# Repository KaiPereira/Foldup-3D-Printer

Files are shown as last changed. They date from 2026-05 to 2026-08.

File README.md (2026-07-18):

# Fold up, scissor lift, 3D Printer



This is my fold up, scissor lift, cross-cantilever 3D printer for Open Sauce 2026! It folds up into the size of a small filament box, coming in at just 200x200x75mm in form factor, and has a build area of nearly 80x80x95mm! It is a fully unique 3D printer that utilizes a Positron hotend and a custom HGX Lite bowden extruder and all of it runs off of a simple barrel-jack connector. 

## Custom Features
- Unique scissor-lift, cross-cantilever motion system
- Fits in a filament box and folds up into a 200x200x75mm form factor
- Has a build area of almost 80x80x95mm
- Runs completely off a portable barrel jack connector
- Offline printing using a MicroSD card
- Fast and efficient positron hotend with a custom HGX Lite bowden extruder
- Supports Marlin or Klipper firmware with the BTT SKR MINI E3 V3.0 motherboard
- Looks insanely cool so you can flex at hackathons

## Wiring

The electronics are pretty simple for this project:



## Assembly

### Bill of Materials (BOM)

I bought my parts from Aliexpress, Amazon and then got the aluminum plates cut by PCBWay. 

The BOM isn't too complicated and it also includes some tools that are helpful for assembly, you can access [it here](https://docs.google.com/spreadsheets/d/1xFZ-rjcnBZJ-4SHDmdkzTACUUDvWx6YCcqEs-uq4CdA/edit?usp=sharing).

### CAD

Assembling the board is fairly simple by referencing the [Onshape assembly](https://cad.onshape.com/documents/3a7b565130dc54a0f58628c0/w/db45ce09661f59e4e89ec29b/e/58f0074d6e4db55998381609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).

All the 3D printed/aluminum parts and the entire STEP for the project are accessibly in the [CAD folder](/CAD) too. 

### Firmware

You can just run Klipper firmware for the entire printer. I've left some boilerplate in the [firmware folder](/firmware)!

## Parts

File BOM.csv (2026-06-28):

Item | Amount # | CAD Cost ($) | Usage: | Link | Notes:
Miscellaneous Nuts, Bolts, Screws and Bearings
Bearings | 10 | $13.99 | Bearings for all the scissor lift joints! | https://www.amazon.ca/Pcs-608-2RS-Ball-Bearings-Pre-Lubricated/dp/B0GVV2QJ5G
D8 M6, 16mm Shoulder Bolts | 8 | $6.34 | Shoulder bolts to hold the scissor bearings | https://www.aliexpress.com/item/1005009104127830.html?curPageLogUid=jj2cmFYo2cBi
M3x22mm + 6mm Male to Female Standoff | 4 | $5.82 | These are the special standoffs for spacing the bed from the base of the printer | https://www.aliexpress.com/item/1005004553969515.html?productId=1005004553969515
M3 Nuts | 100 | $3.28 | These are for if I need to lock any of the M3 bolts | https://www.aliexpress.com/item/1005008625622586.html?curPageLogUid=QGnkjvTtCtBt
M8x12mm, 0.5mm Steel Shims | ? | $4.99 | Steels shims to space out the shoulder bolts from other parts | https://www.aliexpress.com/item/1005001878385012.html?curPageLogUid=dnKhIt84hhRM
M6x7.5mm, 10mm Heatset Inserts | 8 | $8.21 | Heatset inserts for securely fastening the M6 bolts | https://www.aliexpress.com/item/1005012009793893.html?curPageLogUid=EhZVAJwp2ZOt
M3x5mm, OD 4.5mm, heatset inserts | 1 | $0.00 | This is the heatset insert for the bowden extruder, tensioner screw |  | DOUBLE CHECK I HAVE
M3x12mm/0.5", socket head cap screws |  | $32.99 | These are the screws for the moving scissor lift carriages | https://www.amazon.ca/Pieces-Screws-Stainless-Washers-Assortment/dp/B09YM913D4?sp_csd=d2lkZ2V0TmFtZT1zcF9hdGY
M3x25mm/1", socket head cap screws |  |  | These are the screws for the STATIC scissor lift carriages
M3x10mm/0.375", socket head cap screws |  |  | These are the screws for the linear rails and other parts
M3x20mm/0.88", socket head cap screws |  |  | These are the screws for the linear rails and other parts
M3x6mm/0.25", socket head cap screws |  |  | For the Y carriage, bolting a linear rail from underneath
M2.5x14mm, socket head cap screws |  | $16.99 | These are the screws for mounting the fan to the positron hotend | https://www.amazon.ca/mxuteuk-480Pcs-Stainless-Assorted-G035-M2-5/dp/B0C7ZRTH3Q?sp_csd=d2lkZ2V0TmFtZT1zcF9hdGY
M2.5x25mm, socket head cap screws |  |  | These are the M2.5 cap screws for mounting the extruders, Nema 11 to the top plate and extruder to the nema 11 from the bottom |  | The length of these can also be changed to be more global
M2.5x8mm, flat head socket cap screws |  | $10.48 | These are the countersunk flat head cap screw for mounting the hotend plate to the positron hotend from the bottom | https://www.aliexpress.com/item/1005012356242603.html?src=google | The length of these can be changed
M3x6mm, flat head socket cap screws |  |  | These are the flat head screws for one of the linear rail mounts for the hotend plate and X axis leadscrew linear rail mount
Stepper Motors
11HS2810-T5X4 | 2 | $85.06 | These are the Nema 11's for my X/Y axes with integrated leadscrews! | https://www.aliexpress.com/item/4000511206852.html?src=google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
35HS34-150N52 | 2 | $100.97 | These are the 2 Nema 14's for the Z axis with integrated leadscrews! | https://www.aliexpress.com/item/1005003623639443.html?curPageLogUid=7hzoTjL6dFmj
11HS2810 | 1 | $26.38 | This is the Nema 11 for the extruder | https://www.aliexpress.com/item/1005005224703770.html?curPageLogUid=pCFCBT3bWVn4
Bed heater, PEI, thermistors and cork
24V 100x100mm Silicone Bed Heater | 1 | $14.37 | This is the heater for the 3D printer bed. The heater is a bit smaller than the PEI sheet, so there's a bit of unheated space, but it'll be fine | https://www.aliexpress.com/item/1005004051777634.html?curPageLogUid=zmOjdQupdsw8
x4 NTC100K XH2.54 1M B3950 | 4 | $4.99 | Thermistors for the bed and MISC | https://www.aliexpress.com/item/32839681093.html?curPageLogUid=jNLwWSrSVgI3
120x120mm Black PEI sheet with base | 1 | $12.48 | This is the PEI sheet for my printer! It's a bit larger than the heater so there's a bit of unheated space on it | https://www.aliexpress.com/item/1005008559095059.html?curPageLogUid=Tv17pzmPMbsf
2x300x600mm cork adhesive | 1 | $10.48 | This is cork adhesive to thermally space the metal base from the metal bed heat spreader | https://www.aliexpress.com/item/1005009769388038.html?curPageLogUid=VJbhgLvk7WmK
Electronics and power
BTT SKR MINI E3 V3.0 | 1 | $39.24 | This is my 3D printer motherboard, with shared Z axis steppers | https://www.aliexpress.com/item/1005003521537547.html?src=google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
24V, 8A DC Power Adapter (barrel jack) | 1 | $29.99 | This will go into the barrel jack mount connector to be separated into wires which will plug into the MOBO | https://www.amazon.ca/Adapter-100-240V-Converter-Voltage-Transformer/dp/B0CBP2KXFB | Amazon because it's safer, more reliable and the price difference isn't crazy
20 AWG, Barrel Jack Mount Connector | 1 | $3.81 | This is the barrel jack mount connector which will separate the power into the 2 wires for the MOBO | https://www.aliexpress.com/item/1005008014808796.html?curPageLogUid=eLFrNRpNAY51 | Just in case that the above barrel jack connectors don't work
Extruder, gears, PTFE
HGX Lite Gear Kit | 1 | $14.28 | These are all the components I need to construct my custom extruder :D | https://www.aliexpress.com/item/1005007313875922.html?src=google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
5mm/0.5M 17T Set Screw Gear | 1 | $3.70 | This is the gear that'll attach to the stepper on the extruder in order to drive motion to the reducing gear | https://www.aliexpress.com/item/1005006755339441.html?scm_id=1007.40050.354490.0&scm-url=1007.40050.354490.0
PTFE Quick Connector | 1 | $3.54 | These are extra PTFE quick connectors for the output of the bowden extruder | https://www.aliexpress.com/item/1005006648870088.html
2m PTFE 2.5x4mm and PTFE cutter | 1 | $6.49 | This is all the PTFE for the printer and extra because I've never worked with PTFE before along with a flush cutter for precise cutting | https://www.aliexpress.com/item/1005010585958289.html?curPageLogUid=Y93xcFtSckLr
Hotend and fans
Positron Hotend | 1 | $0.00 | This is the hotend I'll be using! I got it sponsored from LDO Motors, and the Funssor one is another option if you'd like a cheaper printer | https://lemontron.com/lemontron-rev-e/bom/positron/positron-hotend/
2510 Fan | 1 | $3.81 | This is the main fan for the positron hotend heatsink | https://www.aliexpress.com/item/1005007437708739.html?curPageLogUid=muacLadZQQRl
3010 Blower Fan | 1 | $5.10 | This is the blower fan for cooling the filament once it gets extruded | https://www.aliexpress.com/item/1005007175610610.html?curPageLogUid=ViSXO0x8tRUI
Linear Rails
140mm MGN9H Rails | 4 | $108.36 | These are all the linear rails bought at a standard 150mm size, and are then going to be cut down for my build | https://www.aliexpress.com/item/1005009577277063.html?curPageLogUid=LKLMsBYxQMyv
124mm MGN9H Rails | 2 |  |  | https://www.aliexpress.com/item/1005009577277063.html?curPageLogUid=LKLMsBYxQMyv
134mm MGN9H Rails | 1 |  |  | https://www.aliexpress.com/item/1005009577277063.html?curPageLogUid=LKLMsBYxQMyv
158mm MGN9H Rails | 1 | $18.18 | These are the same rails, but I need to buy the 200mm version to cut down to 158mm | https://www.aliexpress.com/item/1005009577277063.html?curPageLogUid=LKLMsBYxQMyv
Aluminum Plates
120x120mm, 1/8", Custom Aluminum Bed | 1 | $110.00 | The aluminum heat spreader for the bed | PCBWay
180x180mm, 1/8", Custom Aluminum Base Plate | 1 |  | This is the base plate for the entire 3D printer
180x180mm, 1/8", Custom Aluminum Top Plate | 1 |  | This is the top plate for the entire 3D printer
1/8", Custom Aluminum Scissor Lift Arm | 4 |  | These are all the scissor-arms for the 3D printer
Miscellaneous Extra
1kg Green PETG | 1 | $23.99 | This is all the filament for my printer, I'll probably prototype using a different color I already have but I want all green | https://www.amazon.ca/Polymaker-Filament-Strength-Excellent-Compatible/dp/B0FG3KK26X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
Loctite Blue 243 | 1 | $16.61 | Loctite for the shoulder bolts and other components | https://www.amazon.ca/Threadlocker-Strength-Fasteners-Against-Losening/dp/B0C8Z81WQL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
 | Total Theorized Cost (CAD): | $730.93
 | Total Theorized Cost (USD): | $514.94
 | Aliexpress Cart (CAD): | $512.15
 | Amazon Cart (CAD): | $134.56
 | PCBWay Cart (CAD): | $0.00 | Sponsored
 | Actual Cost (CAD): | $646.71
 | Actual Cost (USD): | $455.61

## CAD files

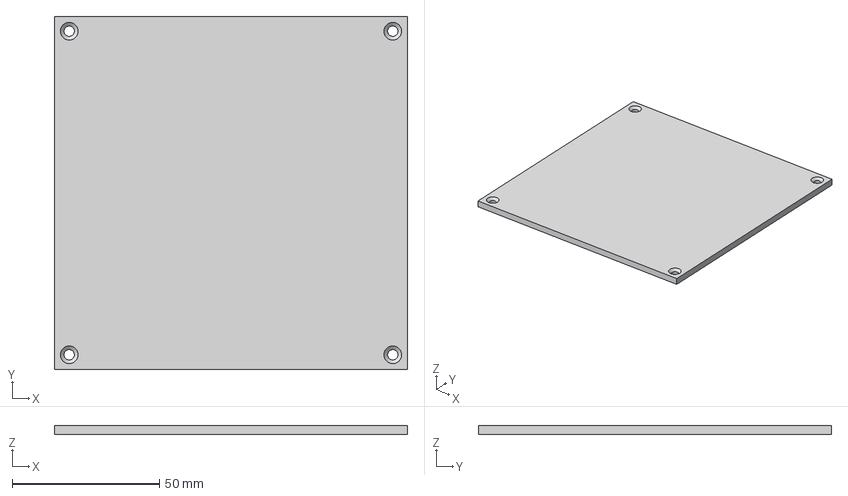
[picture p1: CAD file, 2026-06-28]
CAD/Aluminum Plates/BED_SPREADER.step
120.0 x 120.0 x 3.17 mm

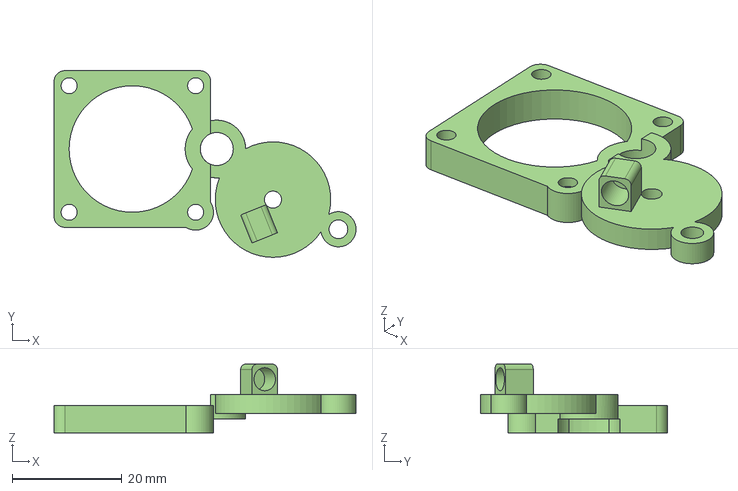
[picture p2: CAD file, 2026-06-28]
CAD/Extruder/Top Extruder Housing.step
54.9 x 34.0 x 12.5 mm

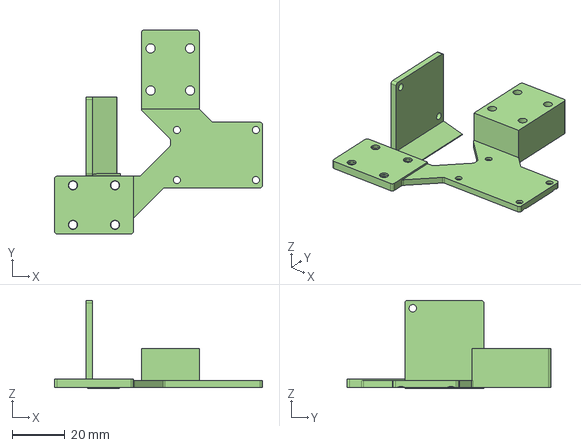
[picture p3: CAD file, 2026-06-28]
CAD/Misc/Hotend Cross-Cantilever Mount.step
79.0 x 77.5 x 33.5 mm

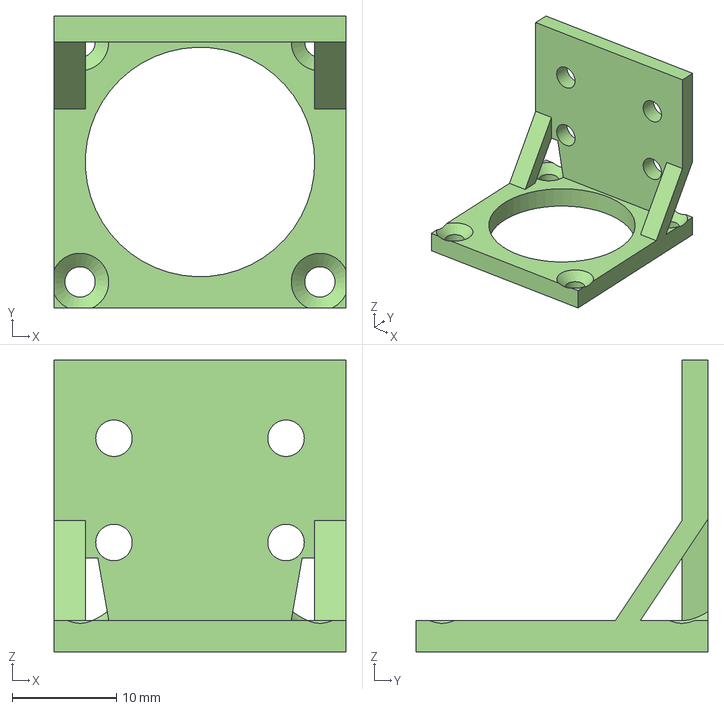
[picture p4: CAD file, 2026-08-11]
CAD/Motor Mount/Top Nema 11 Motor Mount.step
28.0 x 28.0 x 28.0 mm

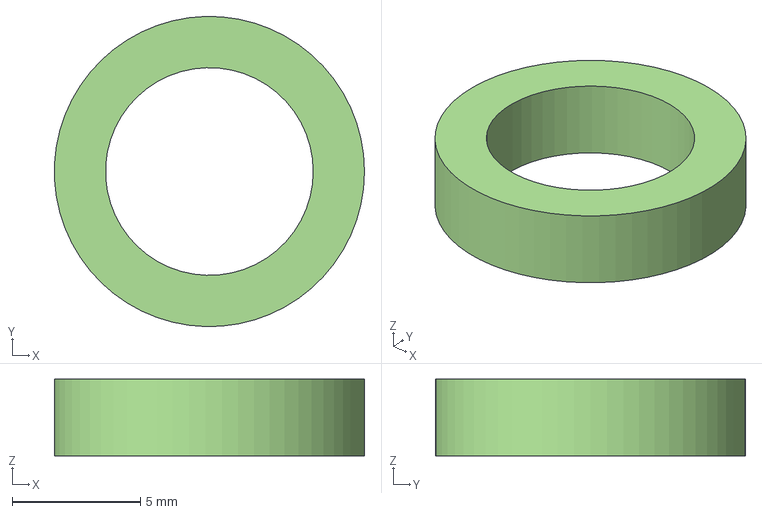
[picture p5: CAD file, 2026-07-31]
CAD/Scissor Lift/Scissor Lift Arm Spacer.step
12.1 x 12.1 x 3.00 mm

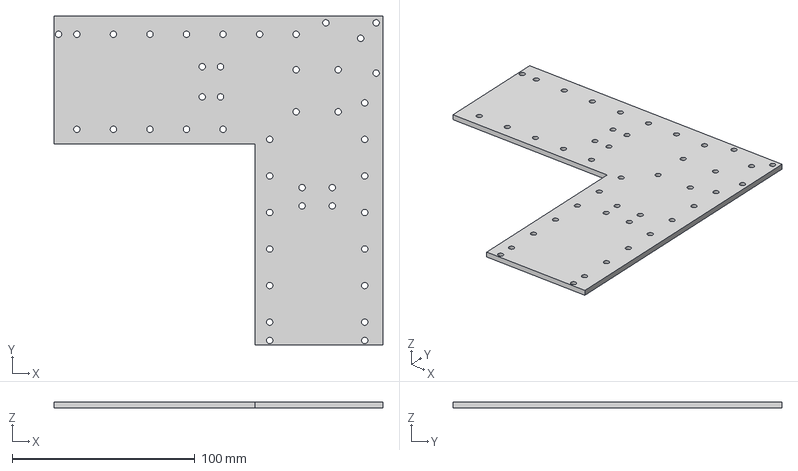
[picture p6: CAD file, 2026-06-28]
CAD/Aluminum Plates/TOP_PLATE.step
180.0 x 180.0 x 3.17 mm

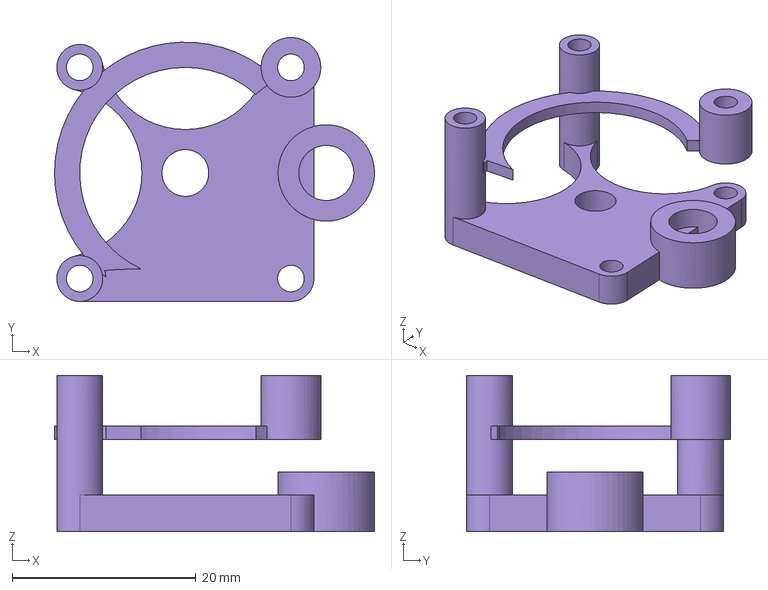
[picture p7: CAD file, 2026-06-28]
CAD/Extruder/Bottom Extruder Housing.step
34.8 x 28.8 x 17.0 mm

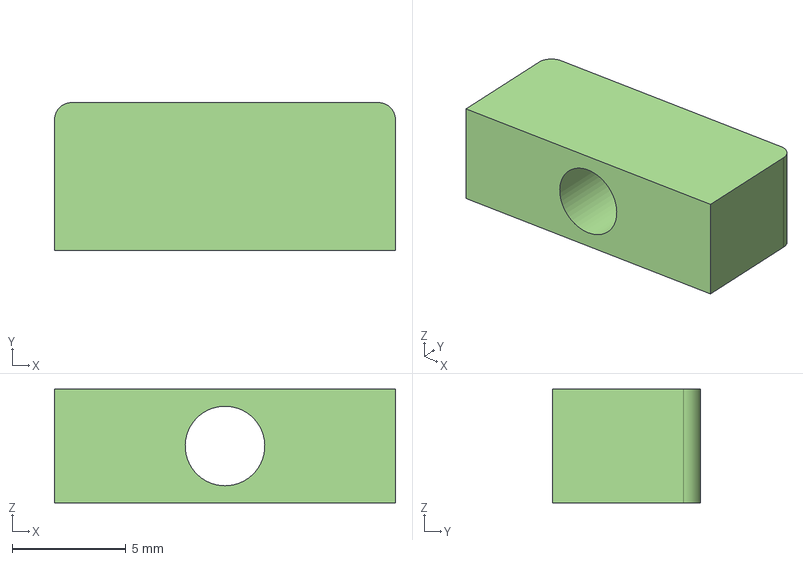
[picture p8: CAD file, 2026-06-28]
CAD/Misc/Linear Rail Endstop.step
15.0 x 6.50 x 5.00 mm

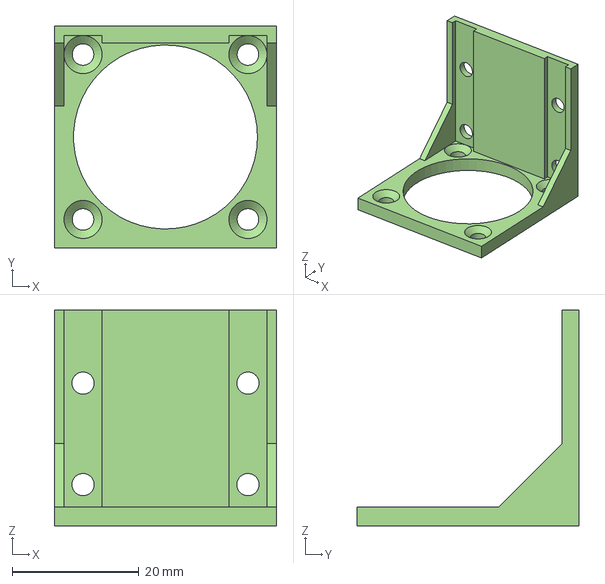
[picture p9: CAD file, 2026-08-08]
CAD/Motor Mount/Bottom Nema 14 Motor Mount.step
35.0 x 35.0 x 34.0 mm

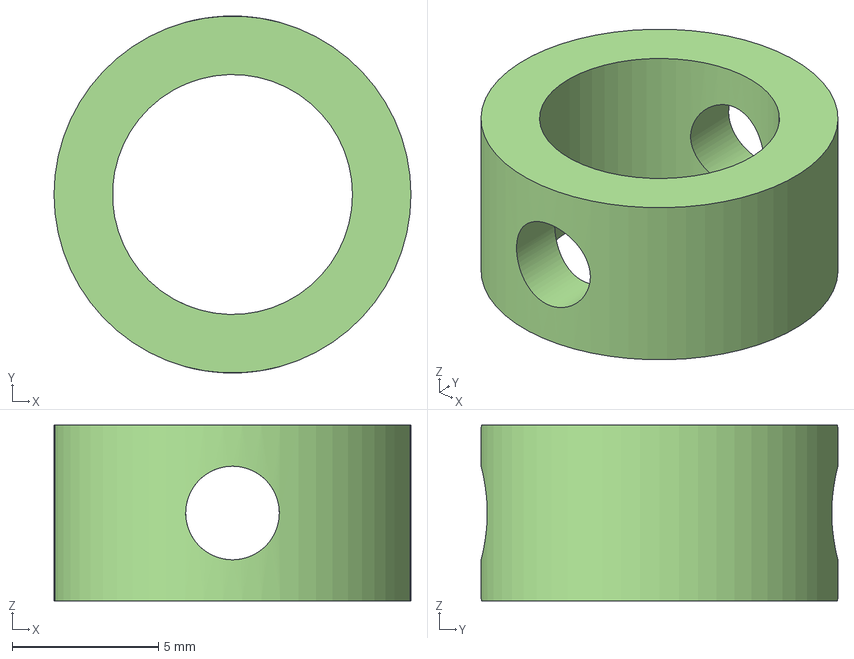
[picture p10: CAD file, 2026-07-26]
CAD/Scissor Lift/Center Scissor Arm Axle Retainer.step
12.2 x 12.2 x 6.00 mm

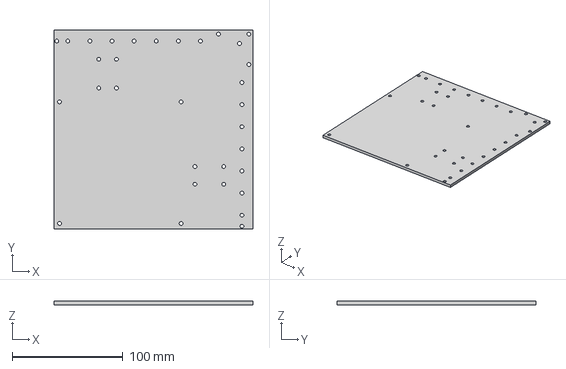
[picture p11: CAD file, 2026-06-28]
CAD/Aluminum Plates/BASE_PLATE.step
180.0 x 180.0 x 3.17 mm

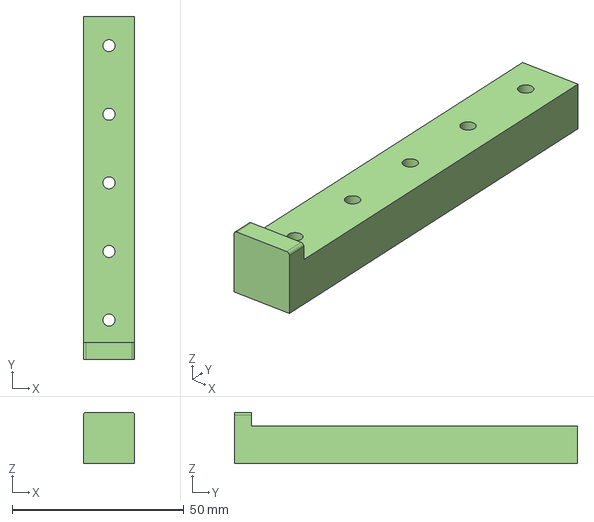
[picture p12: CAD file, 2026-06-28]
CAD/Axes/X-Axis Spacer.step
15.0 x 100.0 x 15.0 mm

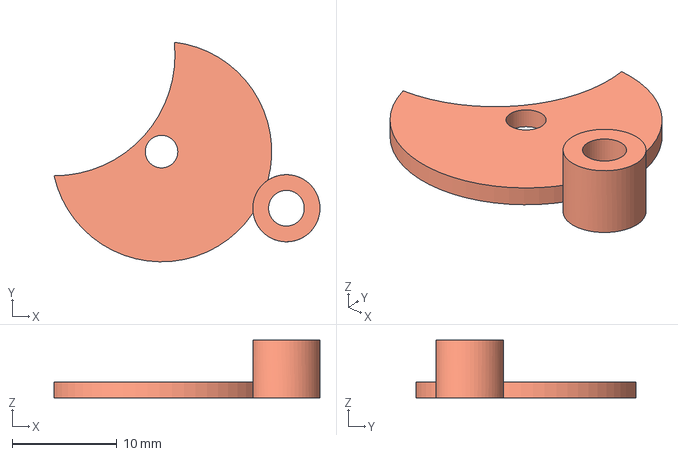
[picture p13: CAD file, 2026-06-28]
CAD/Extruder/Top Extruder Housing - Part 3.step
25.3 x 20.9 x 5.50 mm

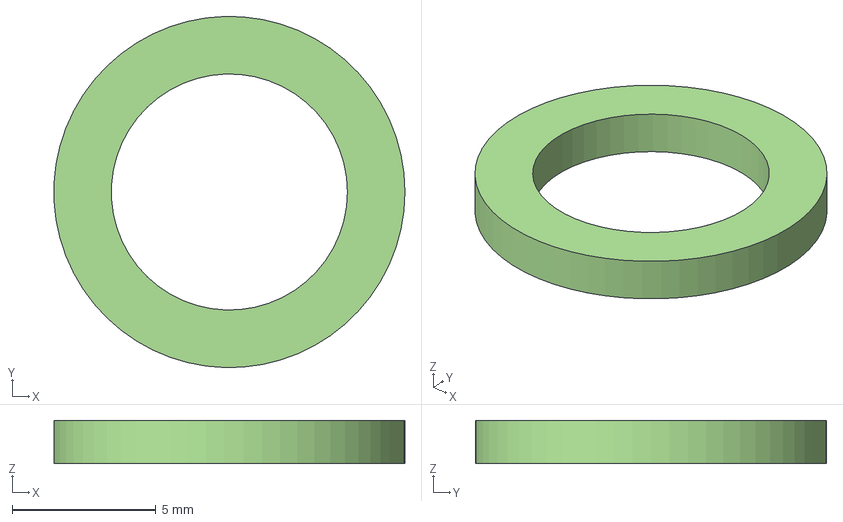
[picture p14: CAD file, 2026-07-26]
CAD/Scissor Lift/Center Scissor Arm Axle Spacer.step
12.2 x 12.2 x 1.50 mm

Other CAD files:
CAD/Aluminum Plates/SCISSOR_ARM.step
CAD/Extruder/Top Extruder Housing - Part 2.step
CAD/Scissor Lift/Center Scissor Arm Axle.step
CAD/Extruder/Top Extruder Housing - Part 4.step
CAD/Axes/X-Axis Leadscrew Mount.step
CAD/Axes/Y-Axis Leadscrew Mount.step
CAD/Scissor Lift/Bottom Scissor Lift Static Mount.step
CAD/Scissor Lift/Top Scissor Lift Static Mount.step
CAD/Scissor Lift/Top, Z-Lift, Carriage Mount.step
CAD/Scissor Lift/X Axis, Z-Lift, Leadscrew Carriage.step
CAD/Scissor Lift/Y Axis, Z-Lift, Leadscrew Carriage.step

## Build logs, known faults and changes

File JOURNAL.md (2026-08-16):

---
title: Foldup 3D Printer
author: Kai Pereira
description: This is my folding, scissor lift, cross-gantry 3D printer I'm working on for Open Sauce 2026!
created_at: 2026-5-6
---
## An idea was born! - 7 Hours

I design a lot of circuit boards that I do a lot of basic CAD for too. Like if I ever design a keyboard, I'll make a keyboard case, if I make a radio I make a little weather station out of it, etc.

Last summer, I designed my own 3D printer motherboard, and it's made me really antsy to design my own foldup printer! So; I've spent quite a few hours (and a day of skipping school) to come up with the exact type of foldup mechanism I want to do, alongside some other cool specs for it!

My process was fairly simple:
- I wanted to have a decent amount of bed area for if I brought it to hackathons and needed to print something a bit larger
- I wanted it to be able to fit inside of a filament box so it's easy to transport
- Should be made using off-the-shelf parts, and the design shouldn't be insanely overly complex.

After many hours, I came up with my brain-child! A folding, scissor lift, cross/double cantilever 3D printer. It's essentially a combination of this cross-cantilever, and the X-printer:

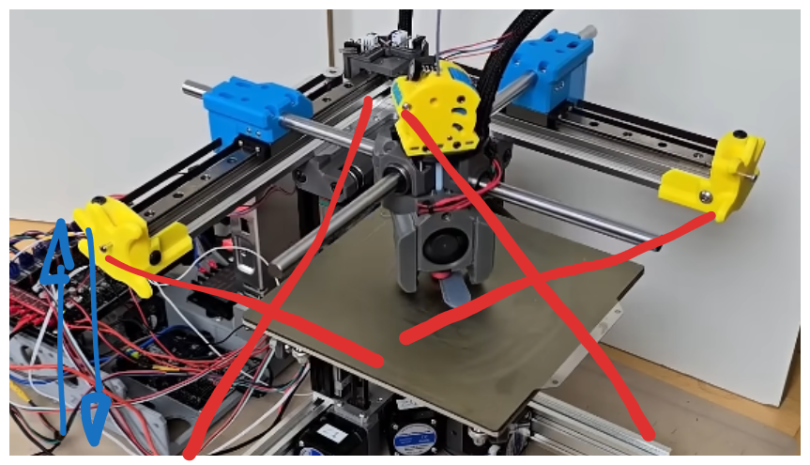
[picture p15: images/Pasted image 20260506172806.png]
Pasted image 20260506172806.png


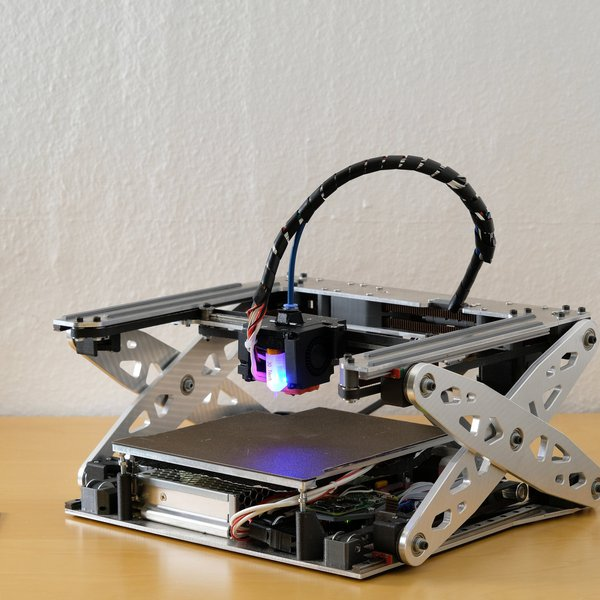
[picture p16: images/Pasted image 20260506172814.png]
Pasted image 20260506172814.png


It took me a really long time to come up with this sort of concept, but I think it'll be insanely cool, a bit complicated and also sacrificing a bit of bed space, but worth it for the insanely cool project!! 

I went through about 10 different concepts, and while some would definitely work better, I think this one is the coolest by far!

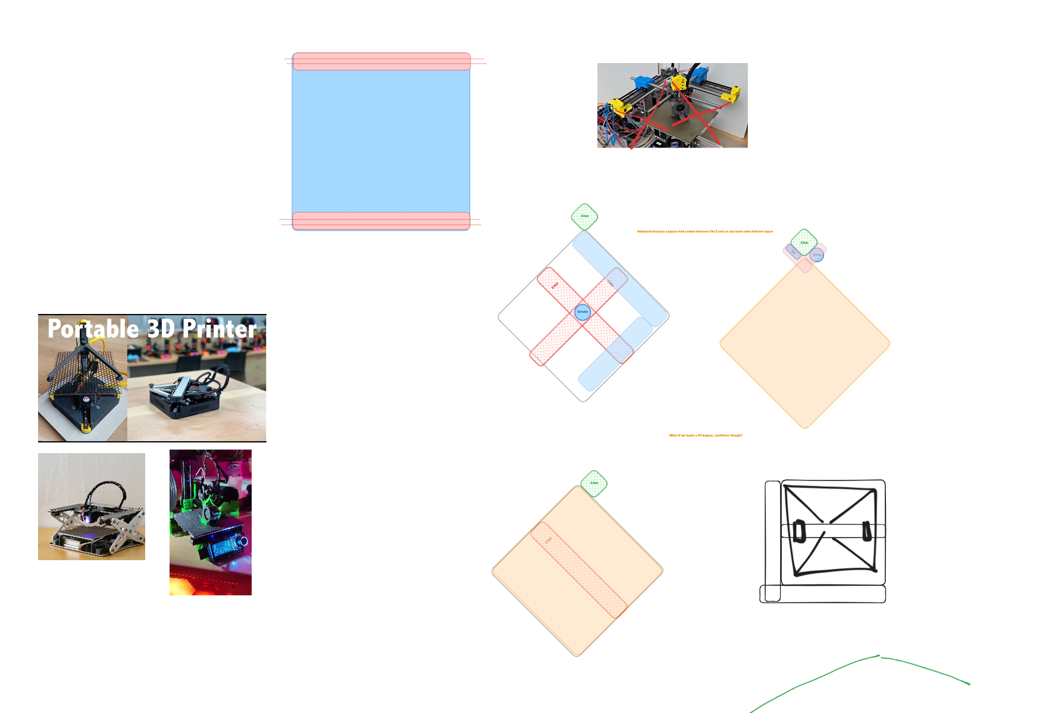
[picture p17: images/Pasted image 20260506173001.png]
Pasted image 20260506173001.png


So let's get into designing this thing!!

## Setting up my CAD workspace and planning - 6 Hours

I like to spend a lot of time thinking exactly how something will come together before putting it actually together, so the next thing I did was think about what parts I wanted to create the base out of and then build it up from them. 

I initially wanted to go with an extrusion approach and even had a pretty good plan for it, but it had some major problems:
- The extrusion was quite tall, so I wouldn't be able to mount the rails on the top faces of the extrusion, or much else so it would be really hard to build a stable printer
- It would be difficult to mount electronics in such a compact frame, and it might be kind of difficult to cut and assemble the entire thing in such a small area.
- Mostly rigidity concerns, I would be working against gravity instead of with it, and the space constrains were really bad.

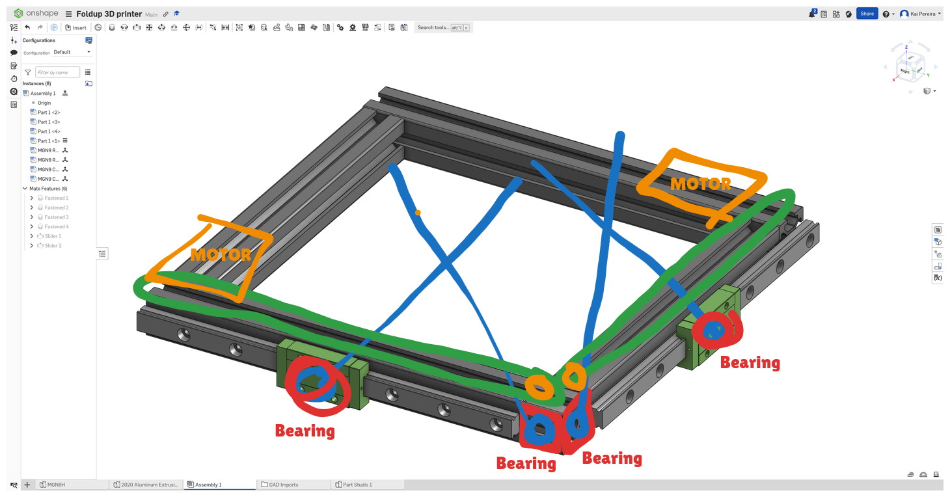
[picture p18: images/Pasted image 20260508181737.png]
Pasted image 20260508181737.png


So i decided to pivot to using 1/8" aluminum plate, just like the X printer, and I came up with a really solid plan for how I want it to work!

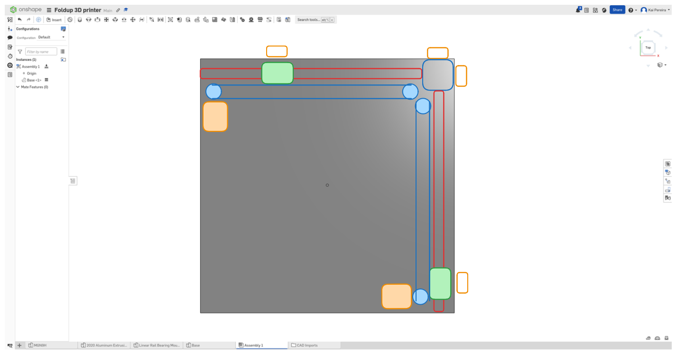
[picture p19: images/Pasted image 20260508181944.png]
Pasted image 20260508181944.png


Nothing's labelled too well but essentially, this gives me a lot of height to work with so I can mount rails to the top and everything else.

Now that I had an actual plan for how I wanted to construct this thing, and a really good vision, I needed to get the basic components in. So I made dynamic models of rails, extrusions, added in bearing models, base plate, just some stuff that would be nice to be able to dynamically add into my model.

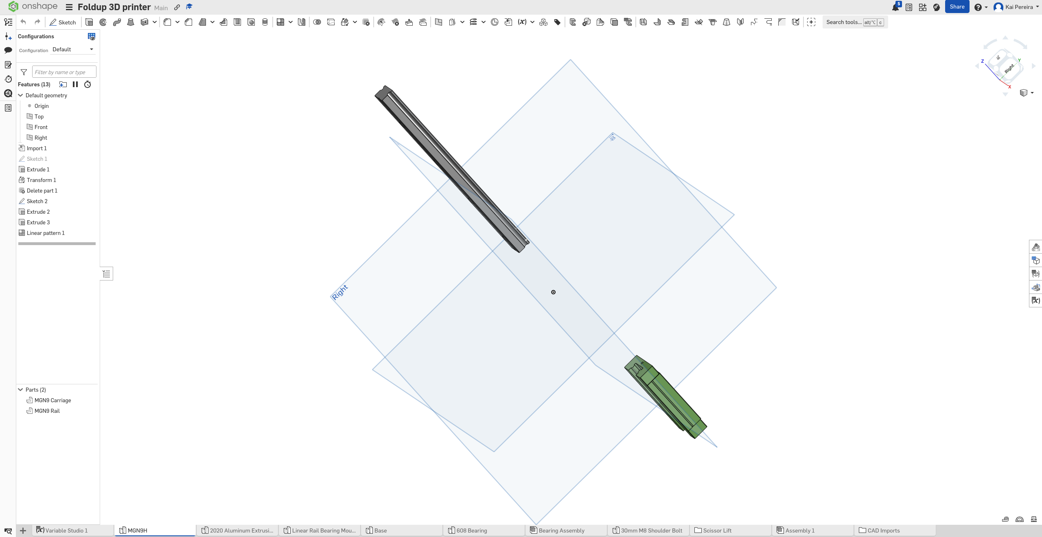
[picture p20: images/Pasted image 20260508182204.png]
Pasted image 20260508182204.png


I did a bit of researching and also decided to use 608 bearings for the scissor lift because they're really accessible, commonly used and a good size. And I also figured out that I wanted to mount my bearings using shoulder bolts, because they would fit really nicely, and they're super strong and polished!

So with all that thinking out of the way, we can get a bit more into designing this thing! 

## Basic scissor lift CAD - 7 Hours

Now that I have lots of the basic components like rails, bearings, and had an idea of the type of mounts I wanted to make, I could actually work on the scissor lift!

The first thing I did, was I made a static mount for the 2 scissor lifts to be fixed to, and then a moving carriage, could move the second part of the scissor lift, allowing it to go up and down.I decided to use a heatset insert + shoulder bolt method because the tolerances are really tight for the bearing to attach onto and it can stiffly attach into the 3D printed block.

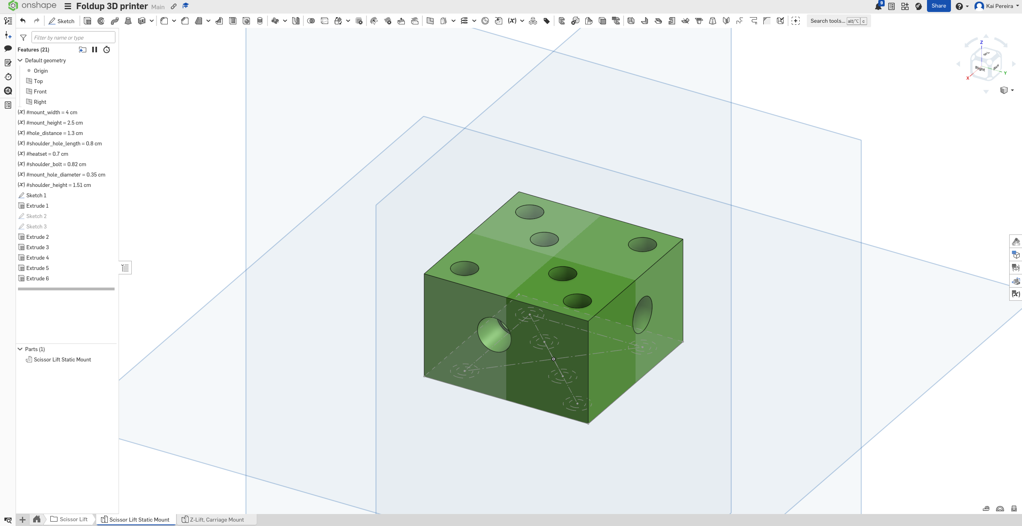
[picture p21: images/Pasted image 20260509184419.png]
Pasted image 20260509184419.png


I've also decided to actively start a BOM, so that I didn't accidentally forget parts, and so I could have all the dimensions, concrete.

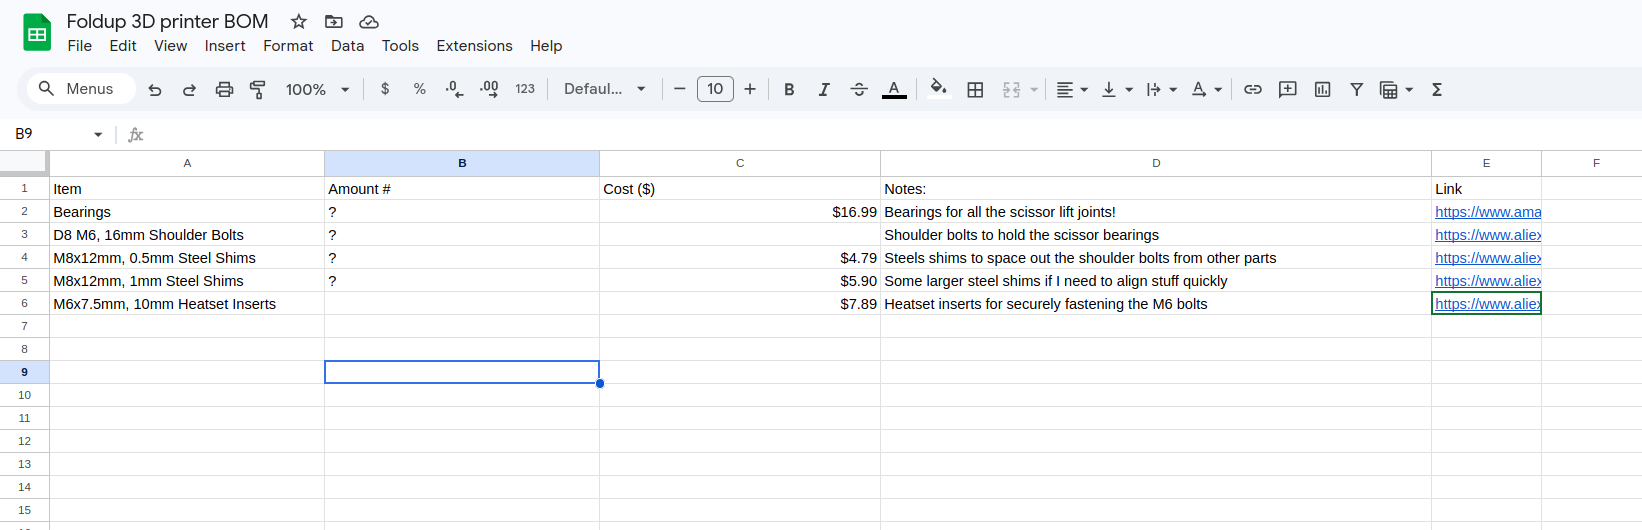
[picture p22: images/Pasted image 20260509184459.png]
Pasted image 20260509184459.png


It wasn't just a smooth process towards creating my mount, but instead lots of revisions and reflecting, while constantly importing the stuff into my assembly and seeing how nicely it fit in.

Next, I made the moving carriage mount for the scissor lift:

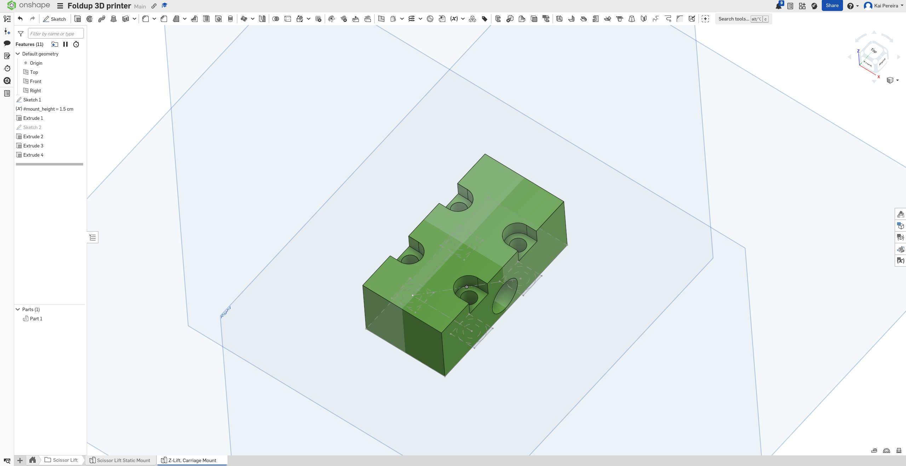
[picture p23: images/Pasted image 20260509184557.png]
Pasted image 20260509184557.png


I'm trying to stick to using M3 bolts for most of this project to minimize my BOM, so you'll notice lots of these components use the same clearances.

And then after lots of revisions, I finally have a simple linear motion system for my scissor lift!

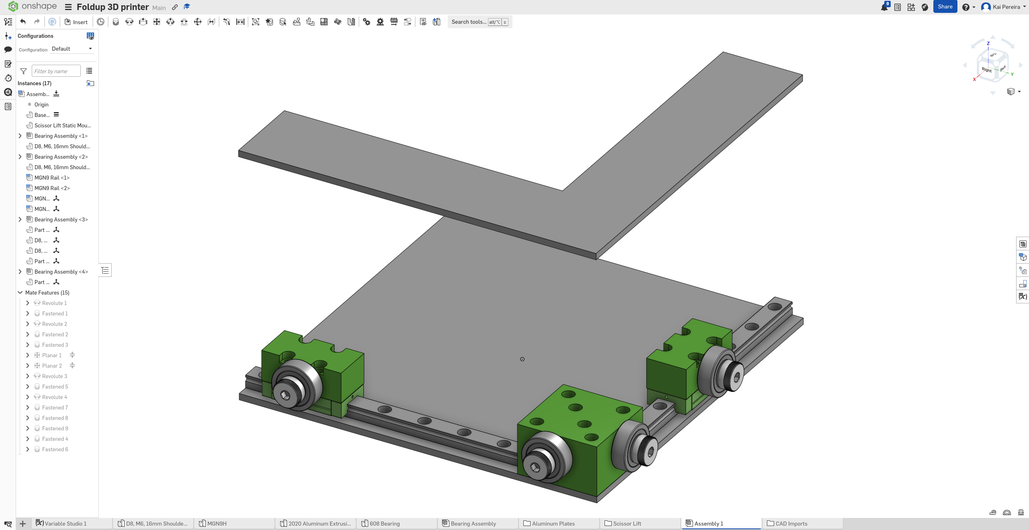
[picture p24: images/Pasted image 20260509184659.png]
Pasted image 20260509184659.png


And then finally, I can just repeat this linear motion system on the top to get my scissor lift motion down!

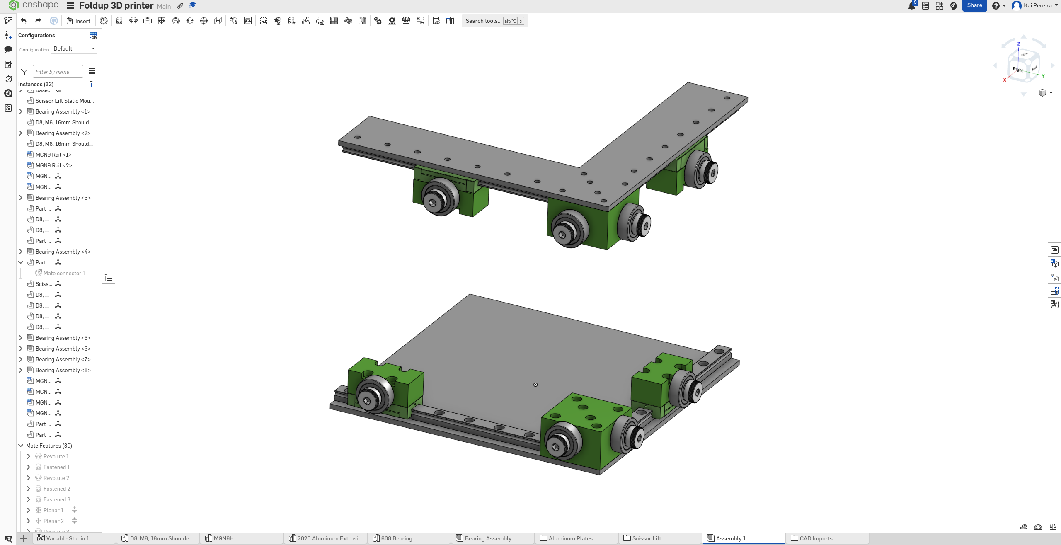
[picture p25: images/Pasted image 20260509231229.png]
Pasted image 20260509231229.png


But this does pose an interesting problem now, because I can't mount the cross-cantilever rails to the top of the plate, or else the whole thing will be too tall, and if I mount it to the bottom of the plate, next to the scissor lift motion, it'll be shorter which also isn't ideal.

So tomorrow, I'll have to figure out this tricky problem, and then I'll also hopefully add in the actual scissors too!

## Scissor lift arms, nuts and bolts - 5 Hours

Now that I have the scissor lift motion system, I can actually add in the arms! 

I decided to keep the material on the arms to be that 1/8" aluminum plate I'm using for the base and top plate, to minimize my BOM, and also because it'll be perfectly fine and 4 plates shouldn't be bending too much. It's also much lighter, so there's less stress on the joints, which is very convenient!

I did a basic model of the scissor arms first so I could get an idea of how they'll fit, and I think it turned out pretty nice!

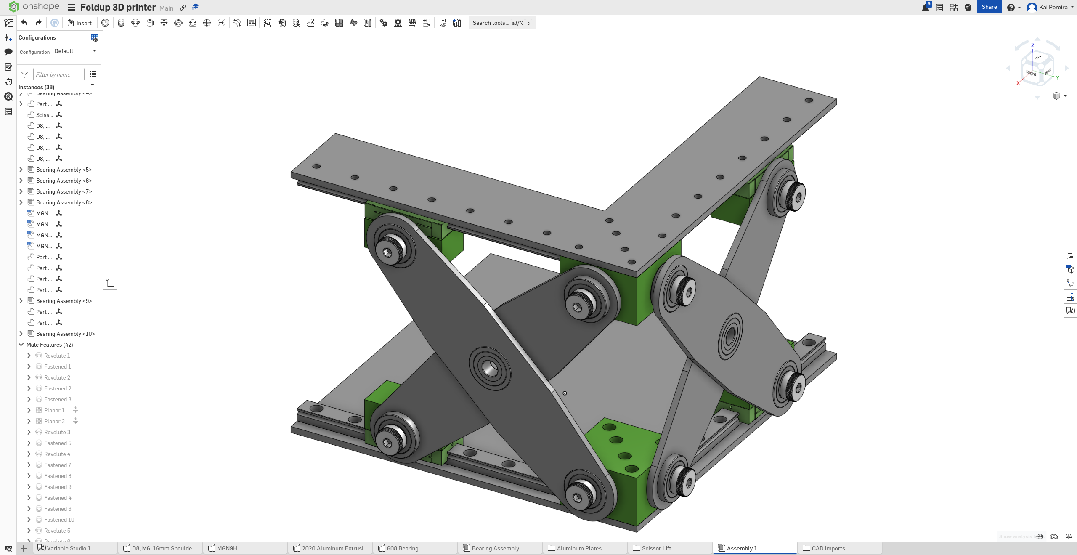
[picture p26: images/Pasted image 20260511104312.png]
Pasted image 20260511104312.png


This gives me about 11cm of Z motion, but I think I can optimize it even more for up to 12/13cm, which I think is pretty good, considering this printer is under 20x20cm! The tolerances are pretty tight and I used -0.001" for the 608 bearing so it's a nice press-fit, and I can thermally expand it if needed.

This only gives me about a mm of spacing which is really tight though, but I think it'll be fine, and might honestly keep everything together, nice and rigidly.

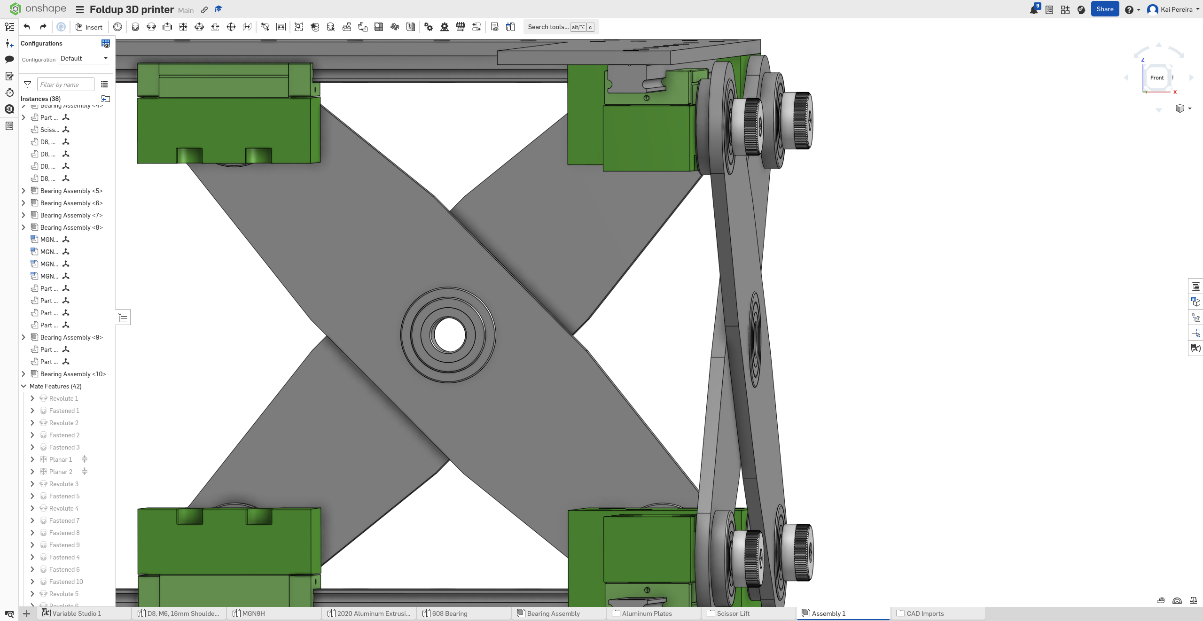
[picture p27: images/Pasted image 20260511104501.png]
Pasted image 20260511104501.png


And now that I have my scissor arms in, let's actually add in all the nuts and bolts to hold together this mechanism together!

I already had all the holes and counterbores for my socket head cap screws (which are really good for rigidity and vibrations), so it was a matter of just adjusting stuff so they fit in nicely with what I was ordering!

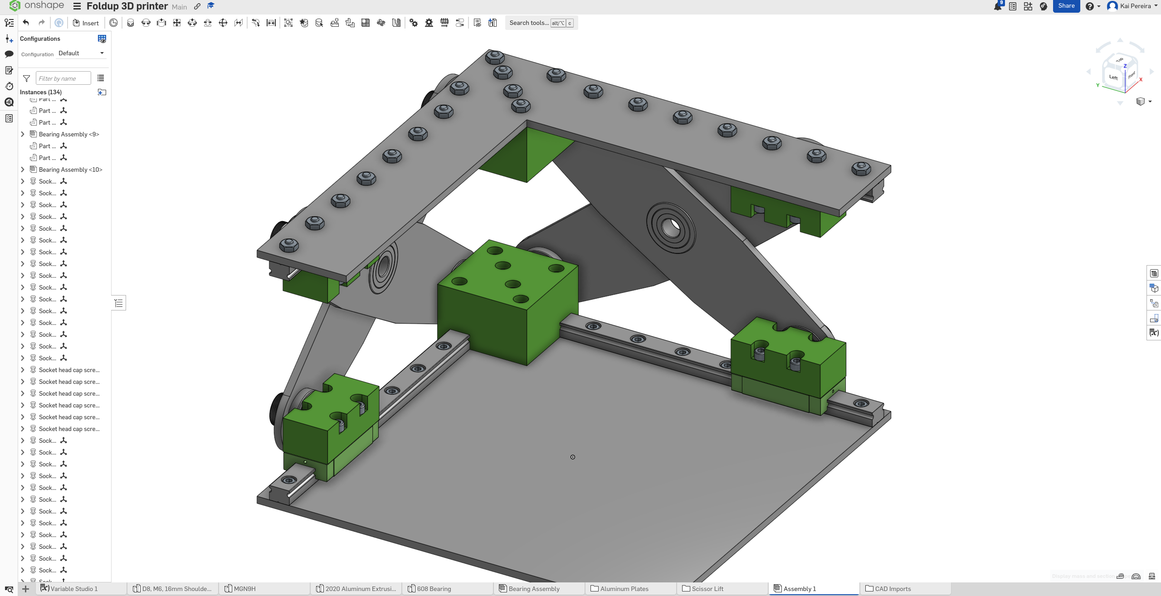
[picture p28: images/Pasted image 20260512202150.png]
Pasted image 20260512202150.png


All the screws are just M3 socket head cap screws which makes the BOM nice and minimal, and they're just of sizes 10mm, 12mm and 25mm!

Now that I have this the actual linear motions parts for this mechanism, I need to make the moving parts, so let's do that next!

## Belts, idlers, drivers and planning - 6 Hours

Now coming into this project, I had no clue how belts actually worked, or their standard sizes. So this led me down the rabbit holes of belts!

The first thing is that 3D printers typically used GT belts and specifically GT2/GT1.5 belts which have their respective pitches. I've decided to use GT2 belts, because they provide more rigidity, being bigger.

Next, there's the idlers and drivers/timing pulley. The idler simply sits fixed on one end so the belt can move freely and then the driver spins from a stepper to drive the whole belt!

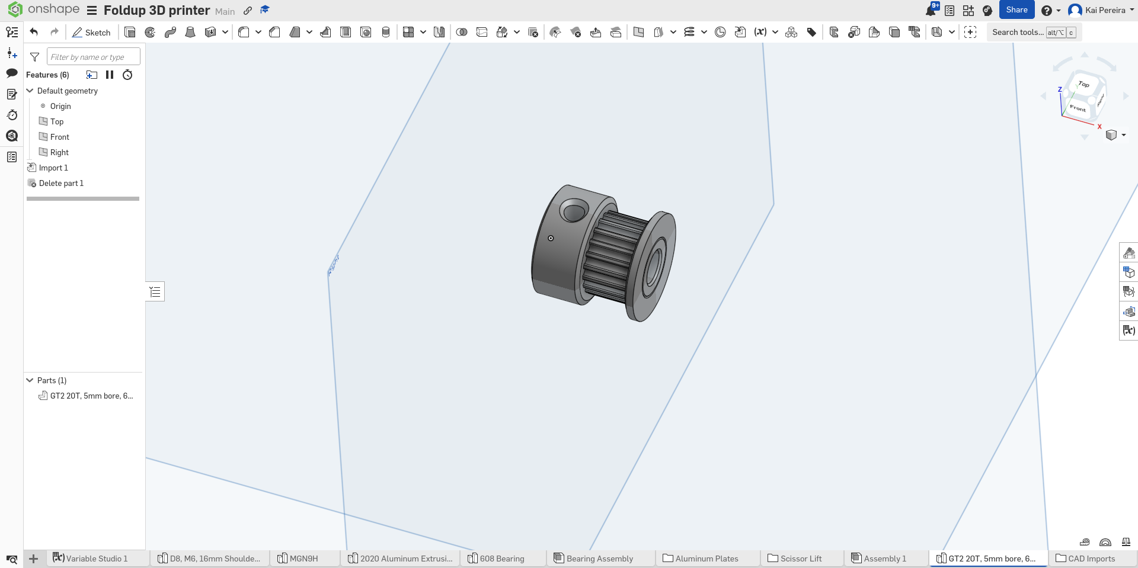
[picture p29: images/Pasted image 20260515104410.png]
Pasted image 20260515104410.png


The driver is attached directly on to the shaft of the Nema 17 and then you can tighten it using the set screws in the driver. 

Next, I wanted to plan out how I was actually going to put on the X/Y axis, so that it wouldn't intersect with any of my belts.

I was on a flight during this process, and decided that mounting them perpendicular to the top plate would be best to minimize space, but I haven't 100% decided on it yet:

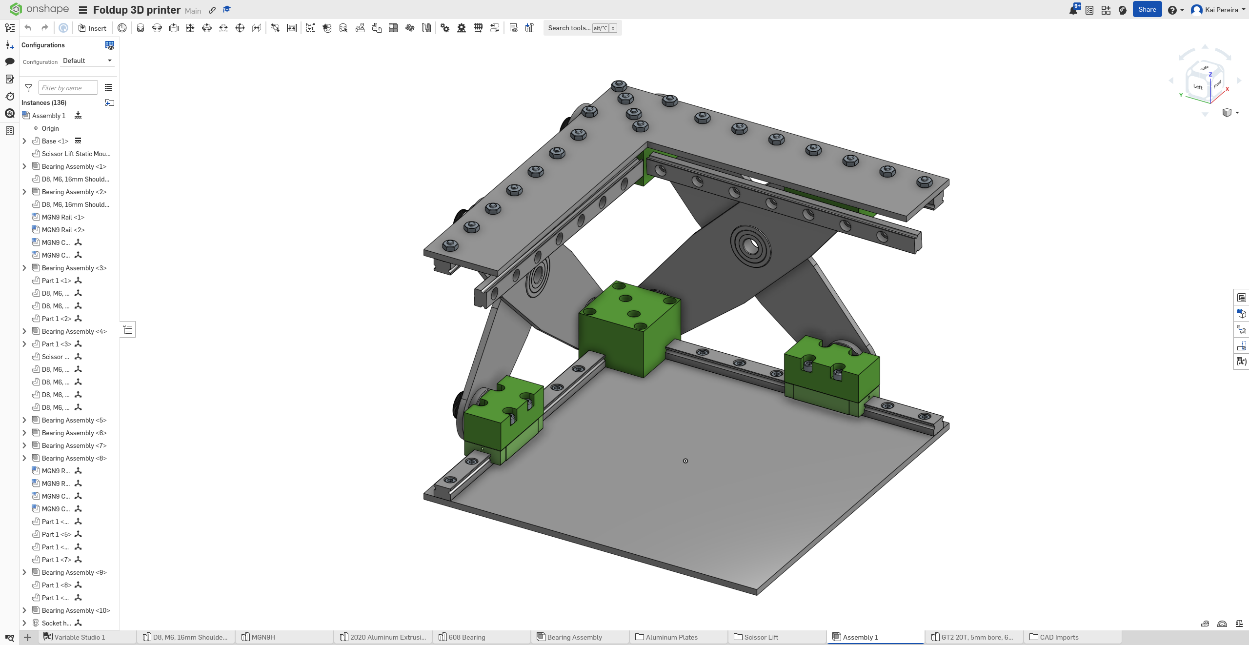
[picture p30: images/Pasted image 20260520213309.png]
Pasted image 20260520213309.png


Now I also need to decide on what type of steppers I want to use!

But before I do that, I think it'll be a good idea to actually figure out how everything will fit onto the printer. I've come up with 2 main concepts that would both work fairly well.

The first system is a fairly complicated, belt-only system:

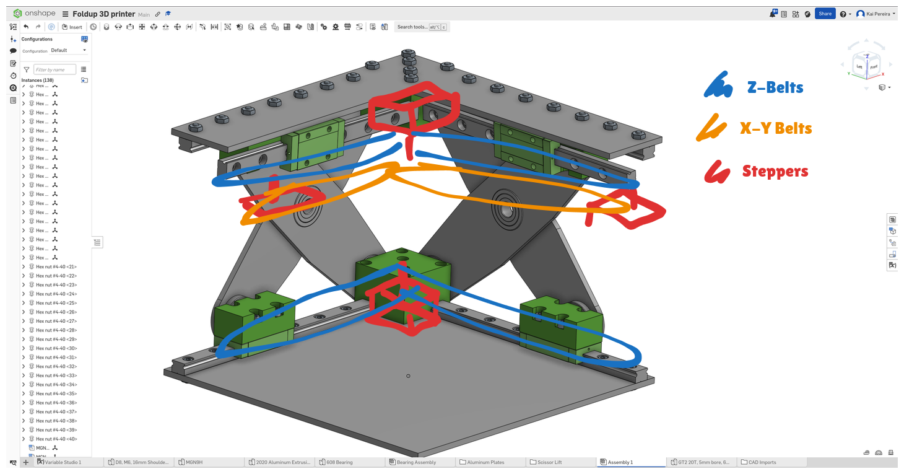
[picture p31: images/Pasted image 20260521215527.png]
Pasted image 20260521215527.png


This one has the advantages of looking cool, and probably being fairly rigid, but it's quite complicated because it uses perpendicular belts, and also takes up quite a lot of space.

The next idea I came up with, with a friend is this leadscrew system:

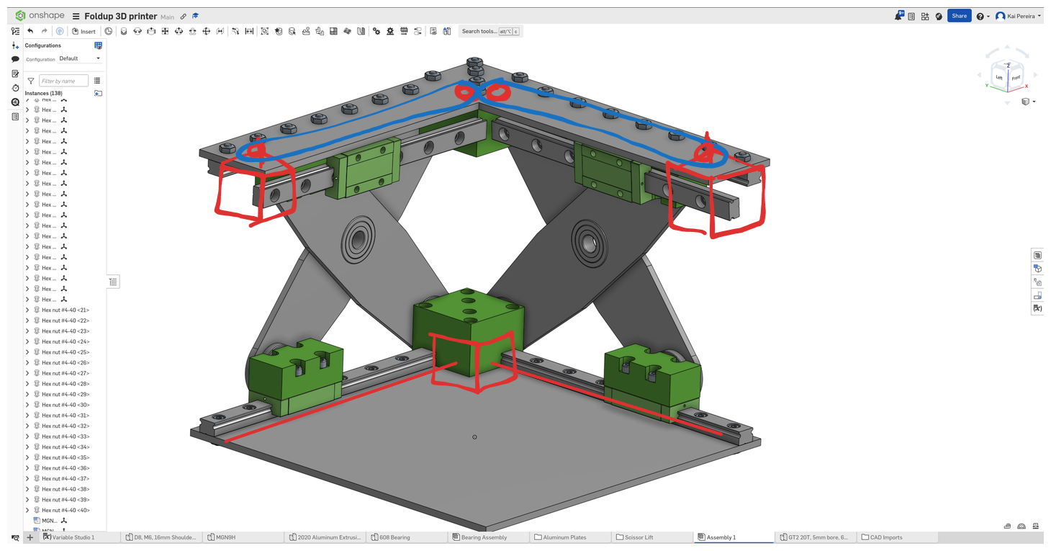
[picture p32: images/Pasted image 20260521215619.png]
Pasted image 20260521215619.png


This one has the advantage of having a really rigid, but slower base, that might be a bit harder to fit in. But the top doesn't have any driving electronics, which is a bit risky in case there's backlash. But it also does open up the opportunity to cleanly mount the X/Y electronics.

I also got a suggestion from this friend to maybe double shear my scissor lift axes or to at least make them more rigid somehow, so I'll have to explore this some more later:

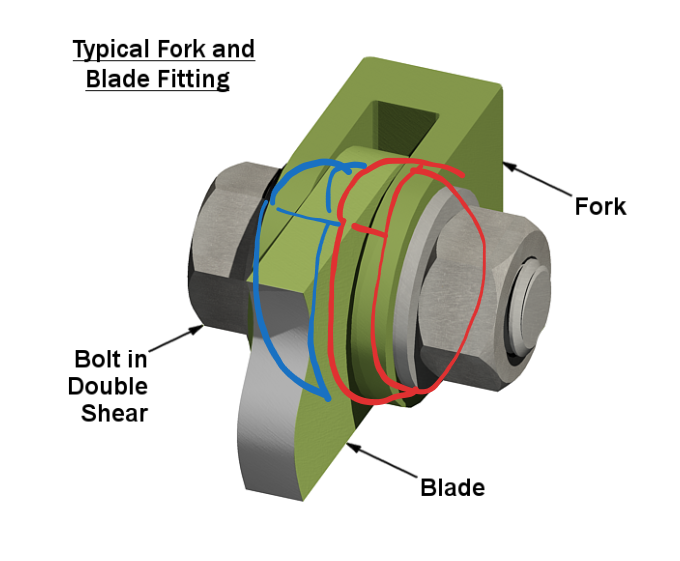
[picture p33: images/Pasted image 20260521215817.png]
Pasted image 20260521215817.png


## Actually assembling the vision - 5 Hours

Now that I've created drawings of where I want to position the electronics, I need to functionally place them in to see if everything will work!

The first thing I got in was the base:

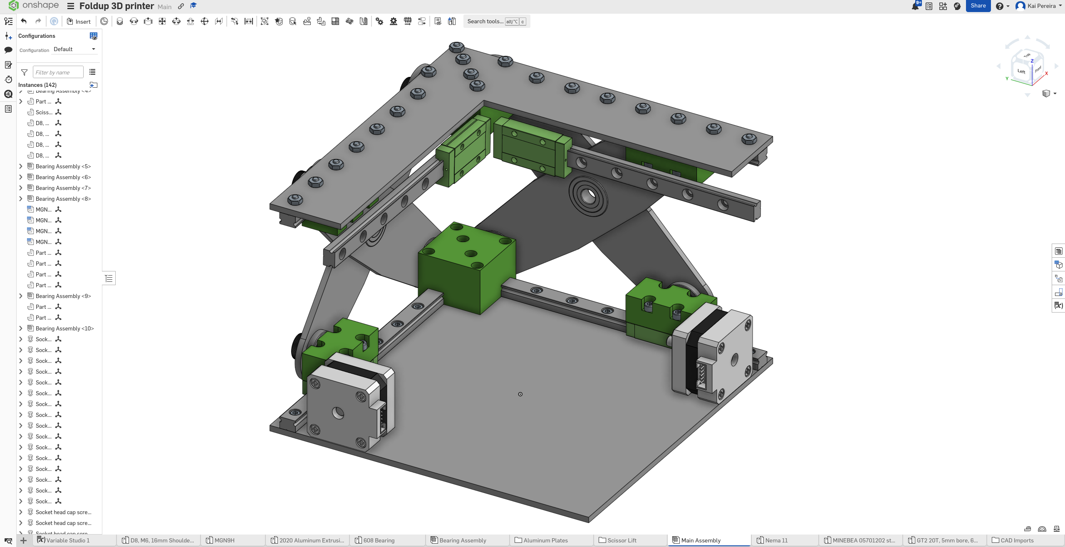
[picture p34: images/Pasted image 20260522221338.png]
Pasted image 20260522221338.png


Doing something like this, will allow me to maximize the motion I can have for my Z, and also make it pretty rigid! I think leadscrews will be significantly better than belts for this, especially considering that the whole system isn't constantly moving up and down, creating backlash.  

Next I need to assemble the X/Y axes! I want to do something like this:

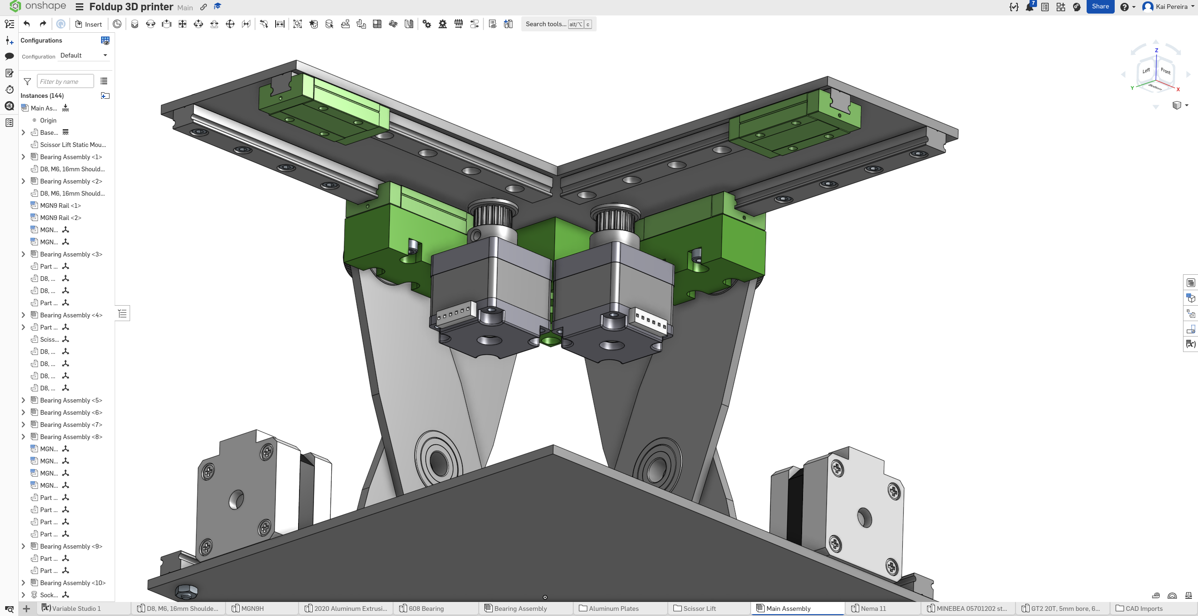
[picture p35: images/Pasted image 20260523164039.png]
Pasted image 20260523164039.png


But, I'm worried that the steppers on the top are going to intersect the leadscrews on the bottom, so I might have to move the steppers upwards, or switch to leadscrews and flip the steppers to be pointing towards the end!

Anyways, I spent wayyy more time and actually fully fleshed out the motion system after quite a bit of iteration!

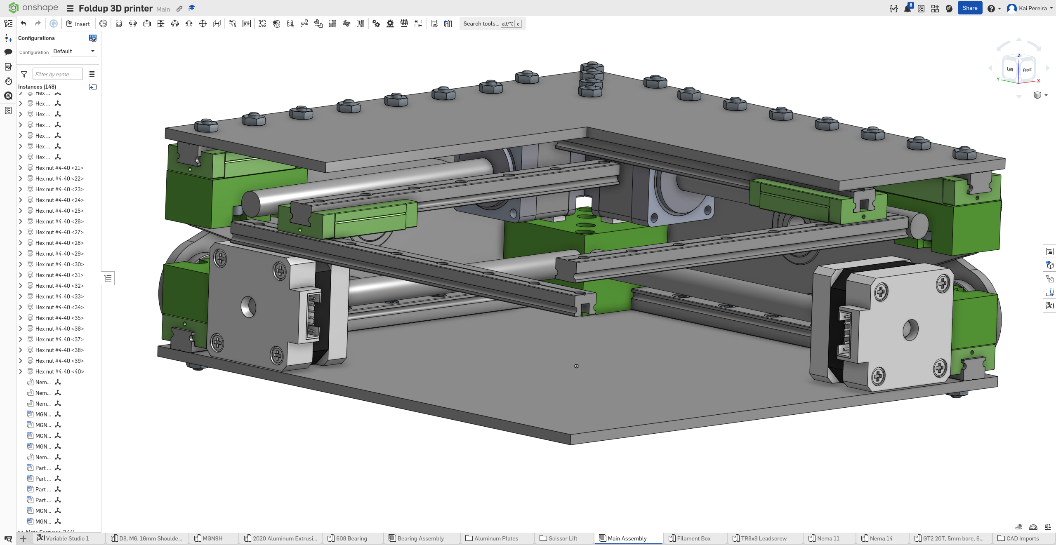
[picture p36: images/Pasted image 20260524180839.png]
Pasted image 20260524180839.png


Every single axis is leadscrews because they're the most space efficient, and I think it'll make all the axes really rigid which is super important for a flimsy, folding printer!  

This is just a mockup of the whole things but it works in theory, and now I just have to properly attach everything! 

## Properly Mounting Everything - 4 Hours

Now that I had everything laid out, I can mount it to the plates. The main things I need to do is create brackets for the motors that will keep them rigidly mounted on a very small profile.

I first created this Nema 14 mount:

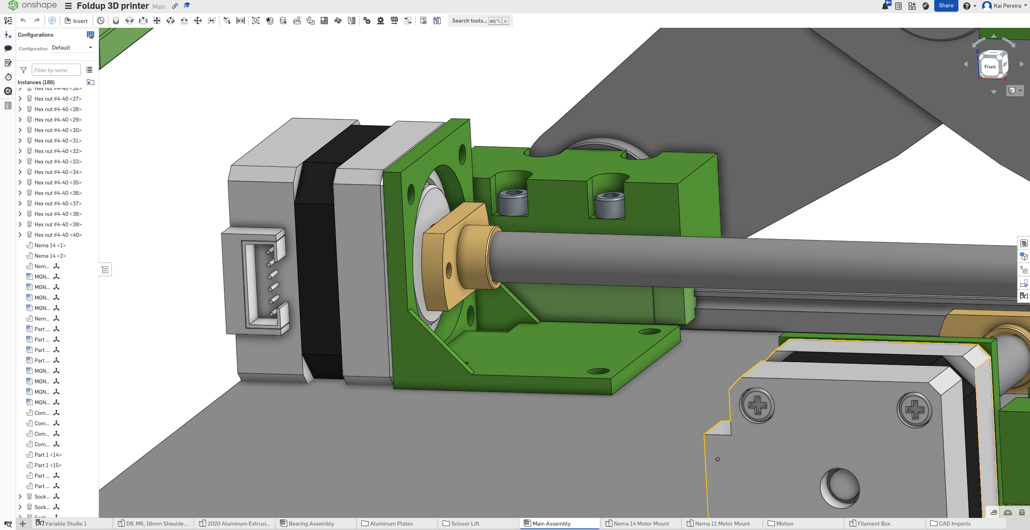
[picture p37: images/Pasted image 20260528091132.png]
Pasted image 20260528091132.png


And then I created the Nema 11 mount:

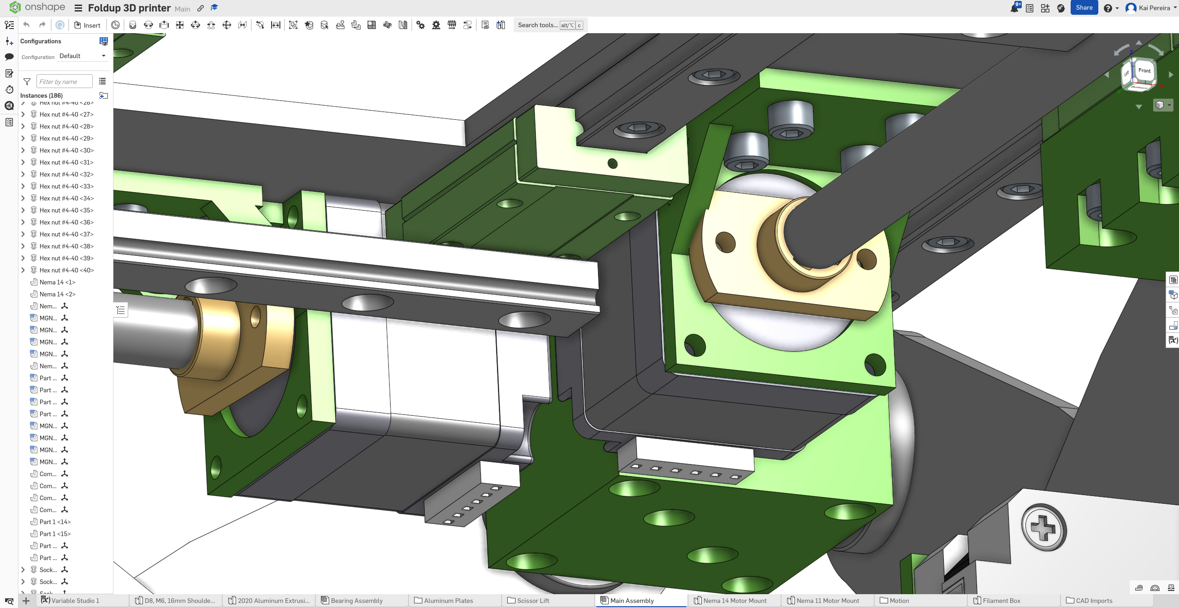
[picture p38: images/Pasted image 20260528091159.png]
Pasted image 20260528091159.png


After a bit of trial and error, I got everything nicely mounted on:

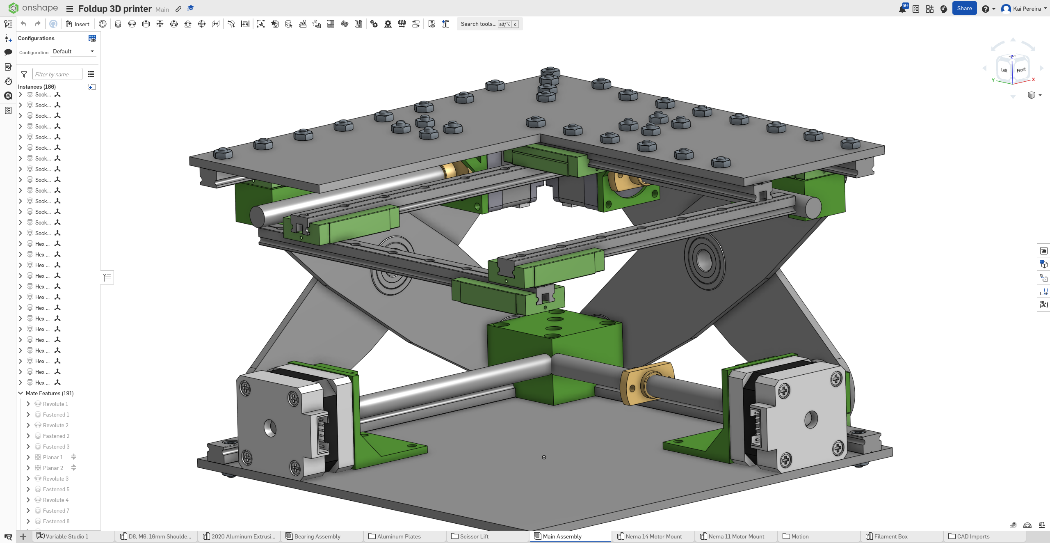
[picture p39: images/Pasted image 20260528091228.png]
Pasted image 20260528091228.png


I still have the X/Y axes to rigid mount, but those require making mounts that'll also be fixed to the leadscrews which is going to be a whole thing to do, so I want to get everything nicely fitted before getting to that! 

The vision is really coming together though, but this is still a pretty rough assembly that needs some tuning on the sizes and spacings.

## Tuning, major improvements and spacers - 7 Hours

I skipped school and go an insane amount of work done on the printer! 

The first thing I needed to do, was mount the other X/Y axes to the top plate:

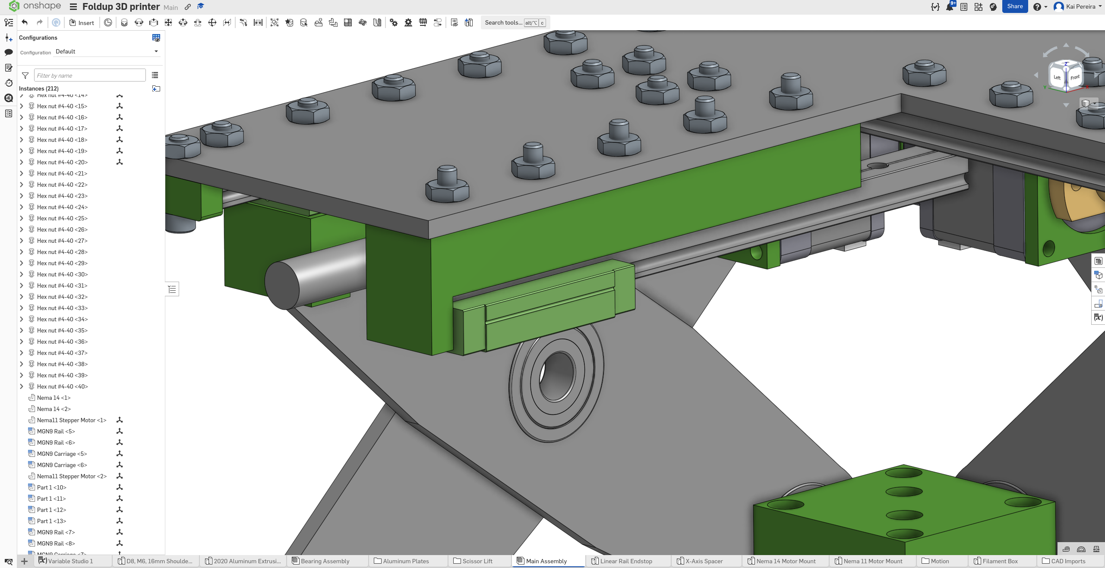
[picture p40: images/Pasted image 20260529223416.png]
Pasted image 20260529223416.png


I decided on a little 3D printed block because I think it'll be rigid enough and it also lets me add the spacer directly onto it!

Next, I added an end-stop to all the ends of the linear rails. This is just a small, 5mm printed block that sites on the end of each rail:

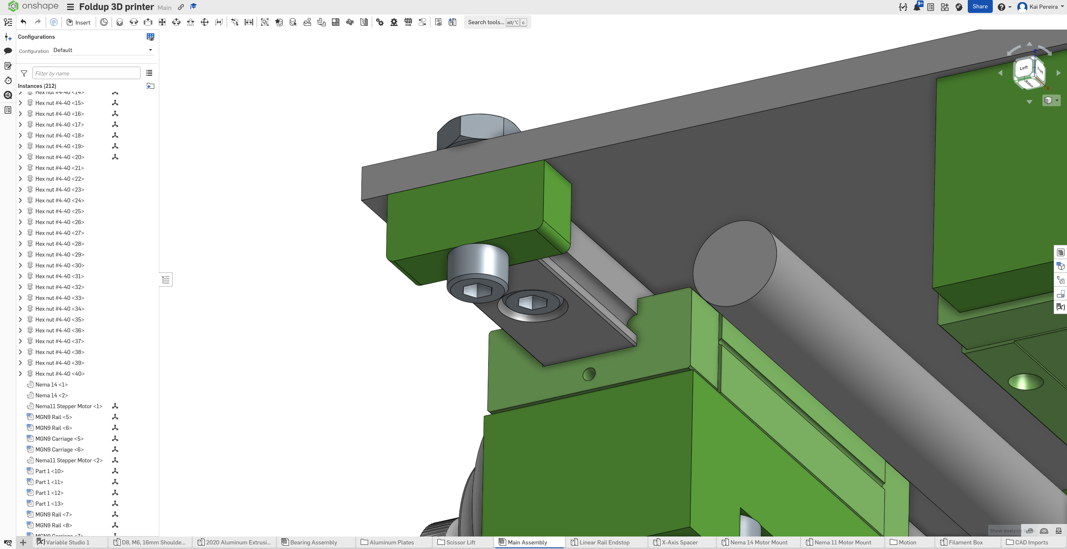
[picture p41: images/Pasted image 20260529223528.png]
Pasted image 20260529223528.png


And then I did an absolute ton of fine-tuning during this process to get everything sitting nicely within the footprint. This took most of my time, but it came out really nicely:

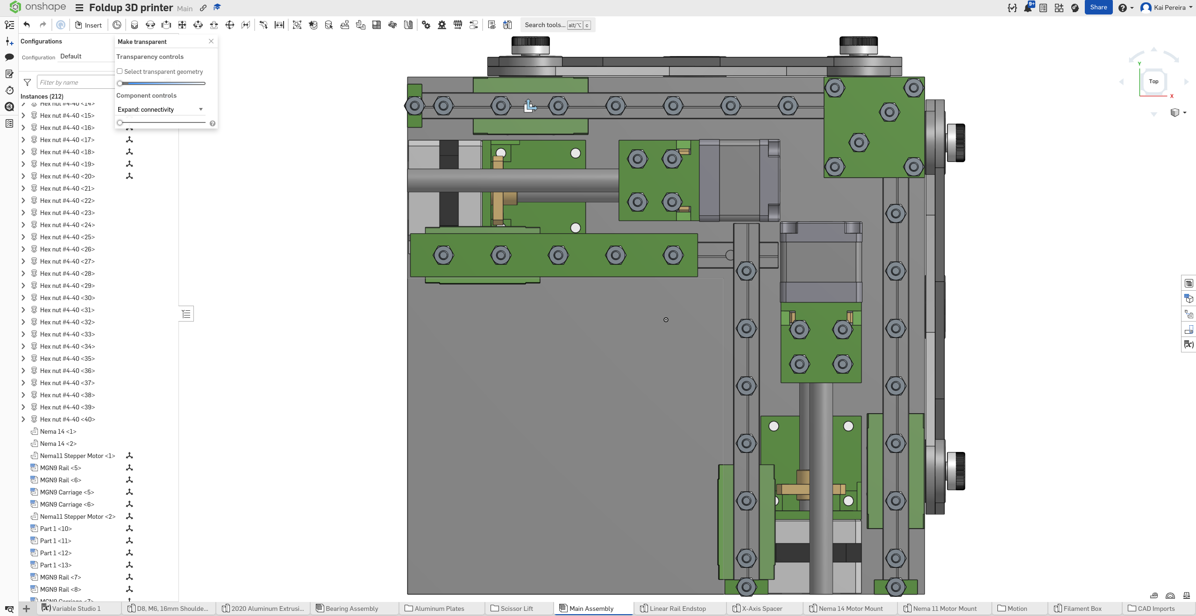
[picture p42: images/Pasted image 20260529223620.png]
Pasted image 20260529223620.png


It took me a ton of time to elegantly do this, but all of this is basically a finished product now. 

Next I figured out how I wanted the cross-cantilever to sit. I did a basic alignment which gave me the outline for how I'm actually going to attach it, but I'm going to leave this for now and onto more pressing matters:

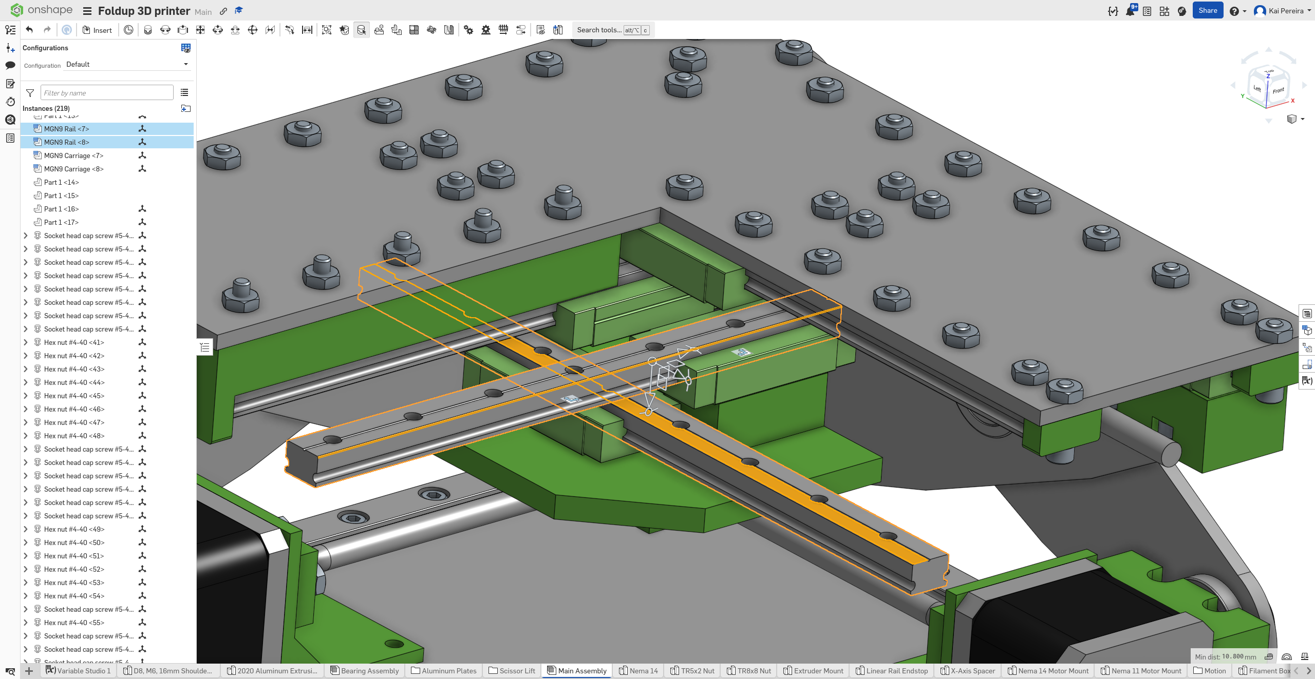
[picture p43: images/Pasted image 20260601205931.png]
Pasted image 20260601205931.png


All I have left is to do the actual cross-cantilever aspect and to add on the extruder, and then I'll be onto doing the electronics! 

## Pause on the X/Y axes - 4 Hours

Now before I actually finish up the XY axes, I need to figure out what motors I'm actually going to use. I spent many hours searching and comparing prices, and the best I found were 2 steppers that were identical to what I already had, the only difference was the leadscrews, and the length of the Nema 14, which were perfectly fine.

My steppers have the final specs of :
- Nema 11: 28x28mm, TR5x4, 100mm travel
- Nema 14: 35x34mm, TR5x2, 150mm travel

The nema 14 isn't ideal, but it works ya know. 

Next, I wanted to mount the scissor lift to their respective steppers. This actually took longer than expected, because I had to fix some unconstrained sketches (silly me, don't do that lol), but I got a nice alignment after a lot of fine tuning:

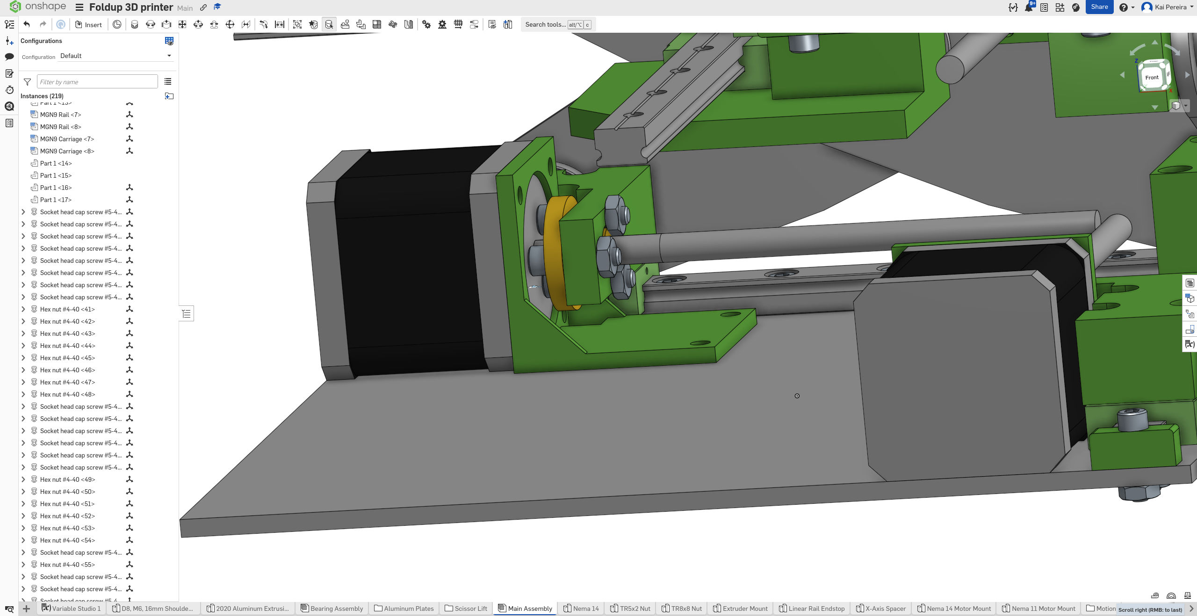
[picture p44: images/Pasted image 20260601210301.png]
Pasted image 20260601210301.png


And this honestly, isn't really ideal because it only gives me 80mm of travel, but I'll do some fine tuning later, and hopefully we can improve that! 

## Wrapping up the axes and starting on the extruder - 7 Hours

Now that I've constrained the lead-screws to their respective stepper, I need to do the same thing but also constrain it to the XY axes. This if fairly complicated because each axis needs it's own special mount, and then they need to be fine-tuned in order to maximize build volume and make space for the toolhead.

So the first mount I made, was this one for the X axis. It's fairly simple but also pretty complicated and I put a 3.5mm slab of PLA, to hole everything together essentially:

Pasted image 20260603220525.pngPasted image 20260603220551.png

Next, I needed to make the Y mount! This one was a bit simpler because it was above everything, so I could just have one slab that connected everything, but it's definitely not quite as rigid, so I might need to make some modifications later. 

Pasted image 20260603220703.png

Looks gorgeous but took me way too long to wrap my head around.

Now I need to fit an extruder onto this though. I'm thinking that I probably want to mount it right in this little sandwich right here, because it basically stands as one of the corners to my bed, which is very convenient!

Pasted image 20260603220829.png

So I did a lot of exploring, testing different extruders to find the most compact one that could fit within this area, and the best I could come up with so far was this:

Pasted image 20260603220916.png

Definitely needs more exploring because this is clearly too tall, but it's not bad a start. This one's a ProtoXtruder V2 with a X1 hotend, and this is actually a pretty good combo, but still too large sadly. So I might have to explore a bowden extruder or something, but we'll save that for tomorrow!

## Refining, electronics and extruder - 10 Hours

After I created all the leadscrew mounts, I did a lot of brainstorming on how I want the extruder to work. It's very important in a cross-cantilever, to minimize the weight on the end of the cantilever because it's going to have lots of flex, and even more the farther out it is which exponentially increases the forces on it. 

Anyways, before I even think about the extruder some more, I know that I need to figure out where the electronics and bed are going to go. The bed is relatively compact in the area of the printer, so I decided to do that all, and constructed a layer of cork as a heat shield, and then the heater + thermistor, aluminum spreader, and then magnetic plate to stick the PEI sheet onto. 

Pasted image 20260606022624.png

Next, I wanted to get the actual height of how small this printer will be when folded up, so I modified the scissor lift to get the smallest printer height, which is over a centimeter smaller then before:

Pasted image 20260606022730.png

That gave me some problems with my previous mounts, because I had to modify stuff so it didn't hit the bottom Nema 14 here, so I redesigned those with some relative ease:

Pasted image 20260606022816.png

Now my idea is to fit all the electronics underneath the bed. I currently have about 62mm between the top of the bed and the top of the printer, so if my electronics take up 30mm of vertical space, then I'll need to make my hotend, just a mere 32mm, which is only possible with a bowden extruder if I'm being honest.

So I currently have a good vision to actually do that and to put the electronics underneath, and then my bowden extruder in the corner of the printer, and then a really small hotend:

Pasted image 20260606023045.png

So the first thing I decided to do, is re-work my bed so that I can fit the electronics underneath it. I decided to make my electronics architecture be an SKR Mini E3 V3.0 with DC barrel jack for input power so that it's nice and portable with no PSU! 

Pasted image 20260608225958.png

Pasted image 20260608230015.png

The bed is countersunk into the standoffs using machine bolts, and I decided to leave enough space so that the hotend mount would just barely not be glazing the printer bed.

Next, I need to work on the extruder. I was lucky and had barely enough space to squeeze in a Nema 11, and it actually gets pretty close torque to a pancake Nema 14 so it should be good enough to extrude PLA with some finesse:

Pasted image 20260608230228.png

It took me a WHILE and quite a few sketches to come up with an extruder design, but I've decided to use a planetary gearbox with thin, but long extruder gears because they weirdly fit in nicely into the design:

Pasted image 20260608230333.png

*To be adjusted*

I made this nice little custom planetary gearbox (which has a very cool assembly >:) which gives me a 5.33:1 gear ratio, which should be good for getting the around 0.4 N-m of torque I need to extrude PLA:

Pasted image 20260608230447.png

And that's the basics of the extruder concept, finished! Now we can get onto finishing it up, and working on the hotend too.

## Finishing up the custom extruder - 16 Hours

Now the planetary gearbox actually fit decently, but if I'm being honest, there's not too much space left for the actual filament drive gears or I can't even put them in a nice spot. Most extruders don't use planetary gearboxes, and instead, just use spur gears to get their, so let's design a new extruder with gears. 

I'm going to use all the parts from the HGX lite extruder and reference the step model of that extruder throughout my design too.

Pasted image 20260609232351.png

This gives me a much cleaner design that I can more easily customize, because I don't have a clunky planetary gear in my mechanism. It also has better access for the filament to travel through the whole mechanism so that I don't have a twisted PTFE tube!

Anyways, next I needed to essentially build off of this current design, to create something more refined, with everything attached. Building an extruder is like building with lego, and you just keep on adding and cutting down stuff until you get something nice and refined.

So after many hours, I came up with this basic, almost working design:

Pasted image 20260610223402.png

The only thing that this extruder is missing, is the PTFE connector fastened to the extruder, and then the path the filament will take. But everything is pretty much properly attached, albeit, pretty terribly.

And it actually fits very tightly within our printer, but it fits nonetheless!

Pasted image 20260610223549.png

Next I needed to add the actual PTFE connector with it's grub screw and the tensioner screw to the design. This is quite tricky, because I essentially need to separate the extruder's top half into 2 additional parts so that you can adjust the  distance between these 2 parts to adjust the tension at the filament driver. 

And after a lot of research, this is what my design looks like:

Pasted image 20260611231017.png

I also did a lot of minor modifications to the bottom and whatnot, but now I actually need to finish it off:

Pasted image 20260611231112.png

Here's how the extruder currently fits inside of the printer:

Pasted image 20260611231142.png

*Very precisely!*

Next, I need to add the output PTFE connector, and then fix everything together, polish up a little bit and then it'll be good! 

So after a lot of procrastination, I got something pretty decent:

Pasted image 20260614225722.png

There's a lot of refining that still needs to happen, but some good progress is happening.

And then just like that, we have a finished extruder, albeit a terrible one:

Pasted image 20260615225505.png

It all fits nicely, so now I can move onto figuring out the hotend!

Pasted image 20260615225555.png

## Finishing the hotend and wrapping up the project - 16 Hours

Now that I've finished the custom bowden extruder, I need to figure out what hotend I want to use.

I have very little clearance for my hotend, so that means I need to pick my hotend very carefully.

These are 4 extruders I decided to first test out:

Pasted image 20260616222705.png

All of these turned out to be too tall except for the mosquito hotend, and then also the [Deltaprint mini hotend](https://www.deltaprintr.com/product/mini-hotend/) , but these are quite expensive. One of my favorite options was the Phaetus Dragonfly BMS which is the blue one, and is quite small and also cheap, but it's still a bit too tall, but there's still a chance that I can alter the design to make it work.

I've reached out to Slice Engineering to maybe get a free mosquito hotend, but I'm still looking at other options, like potentially making a custom extruder from parts from a normal one, by just bodging it a bit.

After a lot of deliberation, I've decided to just go with the positron or the funssor, 90 degree hotends:

Pasted image 20260621221831.png

The funssor hotend is my first choice to buy because it's cheaper, but the positron hotend would easily be better if I could get it sponsored. 

And with that decision out of the way, I can get to actually designing the hotend mount!

Before I do that though, I actually got some responses back from LDO motors and they said that they would sponsor my project with a positron hotend, and potentially some motors/extruder too, so I'll be designing around that hotend!

I needed to adjust all the mounts to allow the clearance underneath some of the linear rails so that I could fit it underneath, but it fits perfectly. 

Now I just need to attach it on, and fix all the mounts, and then wrap up the BOM and then I'll be all done!

The first thing I decided to tackle was the mechanical stuff:
- I created the actual hotend mount and added the fans. I used a 3510 fan because it was the only one that fit in the form factor
- I modified the X/Y leadscrew mounts so that they don't intersect other parts anymore and so that they also work and look better
- Fully assembled everything and added the nuts and bolts

Pasted image 20260627182820.png

The printer is actually fully complete now, and I can move onto the BOM! I had been building out my BOM throughout the entire project, so it didn't take long to complete.

I essentially just had to format and then compile all the prices, and that took me a couple hours:

Pasted image 20260627182934.png

I also included my sponsorships, and the whole projects is actually pretty good, coming in at around $455:

Pasted image 20260627183001.png

After organizing all the files in my repository and creating my readme, this project is officially done!

Pasted image 20260627183031.png

# Building the printer

## Day 1 - Scissor Arms - 7 Hours

I started the first day of building my printer with 3D printing a bunch of parts for the base of the printer, to get an idea of how everything would fit on. A couple immediate problems arose:

 I got shipped the wrong stepper motors, nema 11 linear modules instead of Nema 14 modules. This was bad but also good, because i got to keep 4 linear modules, and was refunded $100 so I could rebuy the parts.
 
The linear rails tolerance for the first hole was a bit off, so only some of them fit kind of nicely onto the plate. This is going to be a bit tricky to fix, but hopefully I can do a good job.

The center of the scissor lift pivot used friction for the scissor lift to pivot around, which is a problem because this can cause the scissor lift to come apart:

Pasted image 20260723192458.png

So now, I have to:
- Re-order the nema 14 steppers which will take 2 weeks to come
- Get my linear rails nicely cut, in the future, I should just get these cut to size though
- Fix the design for my scissor lift

Fixing this issue was quite simple but needed a bit of prototyping, but essentially I just put 2 bearings and then put in axle to hold them together:

Pasted image 20260725222024.png

After doing this fix though, the bearings had quite a lot of mechanical play, so I needed to replace the bearings with some higher precision ones I had laying around after a hackathon (thank you so much outpost), but these bearings also didn't fit perfectly into the holes, so I've ordered some loctite to hold them better into place!

So I have everything ordered, and I'm continuing with the build while waiting for the stuff to arrive, and I need to find a place to get my stuff cut!

So lessons learned today:
- Check the precision specs on your parts, and also buy preloaded parts to reduce mechanical play
- Get linear rails and other stuff cut to size so you don't have to worry about it yourself
- Proper tools are really important like loctite
- Make sure separately moving parts aren't on a single moving element

## Finishing the scissor arms

So after putting all the heatset inserts into the static scissor lift blocks, it was time to loctite all of the scissor arms.

The first thing I learned is that if you ever design bigger stuff, leave a bit more room on the sides and behind a heatset insert, or else it'll probably melt and create some concaves.

Locking all of the bearings into the scissor arms wasn't too bad, but there were a couple things I should've done better:
- Keeping a separate paper tower to wipe off the liquid
- Not using so many pairs of gloves and instead just wiping them off on the paper towel
- Making sure orientation is good before locking them, which somehow became a problem

Pasted image 20260815195209.png

Just small stuff, but overall it wasn't too bad.

Next, I needed to prepare my linear rails for being cut. The first step is actually deciding how much to cut off each rail and where. Because my rails had bad tolerances, I took off a couple more mm than what I actually wanted on each rail to get make sure that they fit.

Next, I needed to slide off the carriage for the rails. When your linear rail gets cut, there's lots of flakes and dust that come off and impact your carriages. So I 3D printed these custom linear rail holders to hold the carriages while they were being cut, so I didn't lose the balls they contained.

While I was waiting on my rails to get cut, I assembled a bit more of the printer, like some printed bits, and a bit of the bed. 

Another problem I came across, is that the motherboard is sitting on bare aluminum, so it's signals will get shorted if it's just lying on it. So I need to figure out some sort of adhesive or something to put on the base to prevent this, which shouldn't be too difficult, but it's a bit annoying.

So after all of this, I got my rails and leadscrew cut. I made a post on my local Reddit forum, and one of the makerspace people offered to do it for me, so I met up with them the next day, and got it done, which was really awesome! 

Pasted image 20260815194913.png

Next, I needed to clean the rails. I did a 3 step process:
- Wipe out the swarf with Q-Tips
- Blow compressed air through the linear rail grooves
- Wipe with a microfiber cloth and 99% isopropyl so it didn't rust



I then mounted these rails onto my frame, which makes it look amazing!

Next, I needed to cut a couple things myself though. I wish I could've gotten the makerspace guy to cut my leadscrews too, but they arrived a bit too late, so I needed to do it myself. A hacksaw doesn't work create for this type of stuff, so I instead opted to use my dremel, which I conveniently have! 

The only cut-off disc I had was a reinforced carbon disc, but it actually worked pretty well. I just wrapped some tape around the thread, clamped the thread in with a wood voice, and then chopped away and polished with a sanding tip. 

So I had a lot of these submodules created, but now I needed to attach them all to the frame. It was pretty simple, I just bolted them on, and the only problems I faced was that my Nema 11 motor mounts can't be bolted into the motors, because I can't physically squeeze a screw through, so I just need a short re-design!

Image from iOS 1.jpg

After doing all of that, I simply assembled everything, and it looks pretty good so far! 

Pasted image 20260813213310.png

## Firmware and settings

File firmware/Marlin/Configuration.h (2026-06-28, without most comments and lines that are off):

#pragma once
#define CONFIGURATION_H_VERSION 02010206
#define STRING_CONFIG_H_AUTHOR "(none, default config)" // Who made the changes.
#define SHOW_BOOTSCREEN
  #define MOTHERBOARD BOARD_RAMPS_14_EFB
#define SERIAL_PORT 0
#define BAUDRATE 250000
#define X_DRIVER_TYPE  A4988
#define Y_DRIVER_TYPE  A4988
#define Z_DRIVER_TYPE  A4988
#define E0_DRIVER_TYPE A4988
#define EXTRUDERS 1
#define DEFAULT_NOMINAL_FILAMENT_DIA 1.75
#define TEMP_SENSOR_0 1
#define TEMP_SENSOR_1 0
#define TEMP_SENSOR_2 0
#define TEMP_SENSOR_3 0
#define TEMP_SENSOR_4 0
#define TEMP_SENSOR_5 0
#define TEMP_SENSOR_6 0
#define TEMP_SENSOR_7 0
#define TEMP_SENSOR_BED 1
#define TEMP_SENSOR_PROBE 0
#define TEMP_SENSOR_CHAMBER 0
#define TEMP_SENSOR_COOLER 0
#define TEMP_SENSOR_BOARD 0
#define TEMP_SENSOR_REDUNDANT 0
#define DUMMY_THERMISTOR_998_VALUE  25
#define DUMMY_THERMISTOR_999_VALUE 100
#if TEMP_SENSOR_IS_MAX_TC(0)
  #define MAX31865_SENSOR_OHMS_0      100 // (Ω) Typically 100 or 1000 (PT100 or PT1000)
  #define MAX31865_CALIBRATION_OHMS_0 430 // (Ω) Typically 430 for Adafruit PT100; 4300 for Adafruit PT1000
#endif
#if TEMP_SENSOR_IS_MAX_TC(1)
  #define MAX31865_SENSOR_OHMS_1      100
  #define MAX31865_CALIBRATION_OHMS_1 430
#endif
#if TEMP_SENSOR_IS_MAX_TC(2)
  #define MAX31865_SENSOR_OHMS_2      100
  #define MAX31865_CALIBRATION_OHMS_2 430
#endif
#if HAS_E_TEMP_SENSOR
  #define TEMP_RESIDENCY_TIME         10  // (seconds) Time to wait for hotend to "settle" in M109
  #define TEMP_WINDOW                  1  // (°C) Temperature proximity for the "temperature reached" timer
  #define TEMP_HYSTERESIS              3  // (°C) Temperature proximity considered "close enough" to the target
#endif
#if TEMP_SENSOR_BED
  #define TEMP_BED_RESIDENCY_TIME     10  // (seconds) Time to wait for bed to "settle" in M190
  #define TEMP_BED_WINDOW              1  // (°C) Temperature proximity for the "temperature reached" timer
  #define TEMP_BED_HYSTERESIS          3  // (°C) Temperature proximity considered "close enough" to the target
#endif
#if TEMP_SENSOR_CHAMBER
  #define TEMP_CHAMBER_RESIDENCY_TIME 10  // (seconds) Time to wait for chamber to "settle" in M191
  #define TEMP_CHAMBER_WINDOW          1  // (°C) Temperature proximity for the "temperature reached" timer
  #define TEMP_CHAMBER_HYSTERESIS      3  // (°C) Temperature proximity considered "close enough" to the target
#endif
#if TEMP_SENSOR_REDUNDANT
  #define TEMP_SENSOR_REDUNDANT_SOURCE    E1  // The sensor that will provide the redundant reading.
  #define TEMP_SENSOR_REDUNDANT_TARGET    E0  // The sensor that we are providing a redundant reading for.
  #define TEMP_SENSOR_REDUNDANT_MAX_DIFF  10  // (°C) Temperature difference that will trigger a print abort.
#endif
#define HEATER_0_MINTEMP   5
#define HEATER_1_MINTEMP   5
#define HEATER_2_MINTEMP   5
#define HEATER_3_MINTEMP   5
#define HEATER_4_MINTEMP   5
#define HEATER_5_MINTEMP   5
#define HEATER_6_MINTEMP   5
#define HEATER_7_MINTEMP   5
#define BED_MINTEMP        5
#define CHAMBER_MINTEMP    5
#define HEATER_0_MAXTEMP 275
#define HEATER_1_MAXTEMP 275
#define HEATER_2_MAXTEMP 275
#define HEATER_3_MAXTEMP 275
#define HEATER_4_MAXTEMP 275
#define HEATER_5_MAXTEMP 275
#define HEATER_6_MAXTEMP 275
#define HEATER_7_MAXTEMP 275
#define BED_MAXTEMP      150
#define CHAMBER_MAXTEMP  60
#define HOTEND_OVERSHOOT 15   // (°C) Forbid temperatures over MAXTEMP - OVERSHOOT
#define BED_OVERSHOOT    10   // (°C) Forbid temperatures over MAXTEMP - OVERSHOOT
#define COOLER_OVERSHOOT  2   // (°C) Forbid temperatures closer than OVERSHOOT
#define PIDTEMP           // See the PID Tuning Guide at https://reprap.org/wiki/PID_Tuning
#define PID_MAX  255      // Limit hotend current while PID is active (see PID_FUNCTIONAL_RANGE below); 255=full current
#define PID_K1     0.95   // Smoothing factor within any PID loop
    #define DEFAULT_KP  22.20
    #define DEFAULT_KI   1.08
    #define DEFAULT_KD 114.00
#define MAX_BED_POWER 255 // limits duty cycle to bed; 255=full current
#define MAX_CHAMBER_POWER 255 // limits duty cycle to chamber heater; 255=full current
  #define PID_FUNCTIONAL_RANGE 10 // If the temperature difference between the target temperature and the actual temperature
#define PREVENT_COLD_EXTRUSION
#define EXTRUDE_MINTEMP 170
#define PREVENT_LENGTHY_EXTRUDE
#define EXTRUDE_MAXLENGTH 200
#define THERMAL_PROTECTION_HOTENDS // Enable thermal protection for all extruders
#define THERMAL_PROTECTION_BED     // Enable thermal protection for the heated bed
#define THERMAL_PROTECTION_CHAMBER // Enable thermal protection for the heated chamber
#define THERMAL_PROTECTION_COOLER  // Enable thermal protection for the laser cooling
#define USE_XMIN_PLUG
#define USE_YMIN_PLUG
#define USE_ZMIN_PLUG
#define ENDSTOPPULLUPS
#define X_MIN_ENDSTOP_INVERTING false // Set to true to invert the logic of the endstop.
#define Y_MIN_ENDSTOP_INVERTING false // Set to true to invert the logic of the endstop.
#define Z_MIN_ENDSTOP_INVERTING false // Set to true to invert the logic of the endstop.
#define I_MIN_ENDSTOP_INVERTING false // Set to true to invert the logic of the endstop.
#define J_MIN_ENDSTOP_INVERTING false // Set to true to invert the logic of the endstop.
#define K_MIN_ENDSTOP_INVERTING false // Set to true to invert the logic of the endstop.
#define U_MIN_ENDSTOP_INVERTING false // Set to true to invert the logic of the endstop.
#define V_MIN_ENDSTOP_INVERTING false // Set to true to invert the logic of the endstop.
#define W_MIN_ENDSTOP_INVERTING false // Set to true to invert the logic of the endstop.
#define X_MAX_ENDSTOP_INVERTING false // Set to true to invert the logic of the endstop.
#define Y_MAX_ENDSTOP_INVERTING false // Set to true to invert the logic of the endstop.
#define Z_MAX_ENDSTOP_INVERTING false // Set to true to invert the logic of the endstop.
#define I_MAX_ENDSTOP_INVERTING false // Set to true to invert the logic of the endstop.
#define J_MAX_ENDSTOP_INVERTING false // Set to true to invert the logic of the endstop.
#define K_MAX_ENDSTOP_INVERTING false // Set to true to invert the logic of the endstop.
#define U_MAX_ENDSTOP_INVERTING false // Set to true to invert the logic of the endstop.
#define V_MAX_ENDSTOP_INVERTING false // Set to true to invert the logic of the endstop.
#define W_MAX_ENDSTOP_INVERTING false // Set to true to invert the logic of the endstop.
#define Z_MIN_PROBE_ENDSTOP_INVERTING false // Set to true to invert the logic of the probe.
#define DEFAULT_AXIS_STEPS_PER_UNIT   { 80, 80, 400, 500 }
#define DEFAULT_MAX_FEEDRATE          { 300, 300, 5, 25 }
#define DEFAULT_MAX_ACCELERATION      { 3000, 3000, 100, 10000 }
#define DEFAULT_ACCELERATION          3000    // X, Y, Z and E acceleration for printing moves
#define DEFAULT_RETRACT_ACCELERATION  3000    // E acceleration for retracts
#define DEFAULT_TRAVEL_ACCELERATION   3000    // X, Y, Z acceleration for travel (non printing) moves
#define DEFAULT_EJERK    5.0  // May be used by Linear Advance
  #define JUNCTION_DEVIATION_MM 0.013 // (mm) Distance from real junction edge
  #define JD_HANDLE_SMALL_SEGMENTS    // Use curvature estimation instead of just the junction angle
#define Z_MIN_PROBE_USES_Z_MIN_ENDSTOP_PIN
#define NOZZLE_TO_PROBE_OFFSET { 10, 10, 0 }
#define PROBING_MARGIN 10
#define XY_PROBE_FEEDRATE (133*60)
#define Z_PROBE_FEEDRATE_FAST (4*60)
#define Z_PROBE_FEEDRATE_SLOW (Z_PROBE_FEEDRATE_FAST / 2)
#define Z_CLEARANCE_DEPLOY_PROBE   10 // (mm) Z Clearance for Deploy/Stow
#define Z_CLEARANCE_BETWEEN_PROBES  5 // (mm) Z Clearance between probe points
#define Z_CLEARANCE_MULTI_PROBE     5 // (mm) Z Clearance between multiple probes
#define Z_PROBE_LOW_POINT          -2 // (mm) Farthest distance below the trigger-point to go before stopping
#define Z_PROBE_OFFSET_RANGE_MIN -20
#define Z_PROBE_OFFSET_RANGE_MAX 20
#define X_ENABLE_ON 0
#define Y_ENABLE_ON 0
#define Z_ENABLE_ON 0
#define E_ENABLE_ON 0 // For all extruders
#define DISABLE_OTHER_EXTRUDERS   // Keep only the active extruder enabled
#define INVERT_X_DIR false
#define INVERT_Y_DIR true
#define INVERT_Z_DIR false
#define INVERT_E0_DIR false
#define INVERT_E1_DIR false
#define INVERT_E2_DIR false
#define INVERT_E3_DIR false
#define INVERT_E4_DIR false
#define INVERT_E5_DIR false
#define INVERT_E6_DIR false
#define INVERT_E7_DIR false
#define X_HOME_DIR -1
#define Y_HOME_DIR -1
#define Z_HOME_DIR -1
#define X_BED_SIZE 200
#define Y_BED_SIZE 200
#define X_MIN_POS 0
#define Y_MIN_POS 0
#define Z_MIN_POS 0
#define X_MAX_POS X_BED_SIZE
#define Y_MAX_POS Y_BED_SIZE
#define Z_MAX_POS 200
#define MIN_SOFTWARE_ENDSTOPS
  #define MIN_SOFTWARE_ENDSTOP_X
  #define MIN_SOFTWARE_ENDSTOP_Y
  #define MIN_SOFTWARE_ENDSTOP_Z
  #define MIN_SOFTWARE_ENDSTOP_I
  #define MIN_SOFTWARE_ENDSTOP_J
  #define MIN_SOFTWARE_ENDSTOP_K
  #define MIN_SOFTWARE_ENDSTOP_U
  #define MIN_SOFTWARE_ENDSTOP_V
  #define MIN_SOFTWARE_ENDSTOP_W
#define MAX_SOFTWARE_ENDSTOPS
  #define MAX_SOFTWARE_ENDSTOP_X
  #define MAX_SOFTWARE_ENDSTOP_Y
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

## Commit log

2026-05-09 more journaling about bearings and design stuff!
2026-05-13 journaling about scissor arms some more and also nuts and bolts
2026-05-23 journaling about assembling the XY
2026-05-28 ajournaling about mounting
2026-06-02 finishing up the Z axis, not quite done, but almost
2026-06-04 journaling about the XY leadscrew mounts and starting on finding a toolhead
2026-06-09 updating joournal with extruder and bed progress
2026-06-10 journaling about the extruder v2
2026-06-11 journaling about extruder progress
2026-06-12 journaling about the PTFE connector and the tensioning screw
2026-06-14 adding in-progress CAD step
2026-06-15 extruder progress update
2026-06-16 finishing the extruder
2026-06-16 finished the extruder
2026-06-17 journaling about the hotend
2026-06-22 chose a hotend
2026-06-23 got a positron hotend sponsorship
2026-06-26 finaggled the extruder in!
2026-06-28 adding marlin boilerplate
    [Configuration.h, Configuration_adv.h, esp32.csv]
2026-06-28 uploading BOM
    [BOM.csv]
2026-06-28 adding 3D printer CAD files
    [Bottom Extruder Housing.step, Bottom Nema 14 Motor Mount.step, Bottom Scissor Lift Static Mount.step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]
2026-06-28 more CAD files
    [BASE_PLATE.step, BED_SPREADER.step, SCISSOR_ARM.step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]
2026-06-28 new BOM
    [BOM.csv]
2026-07-21 updating bottom static scissor lift mount
    [Bottom Scissor Lift Static Mount.step]
2026-07-24 journaling a bit about the buildg
    [Bottom Scissor Lift Static Mount.3mf]
2026-07-24 new axle for the center of the scissor arms
    [Bottom Scissor Lift Static Mount.3mf, Center Scissor Arm Axle Retainer.step, Center Scissor Arm Axle.step]
2026-07-26 journaling about my learnings
    [Center Scissor Arm Axle Retainer.step, Center Scissor Arm Axle Spacer.step, Center Scissor Arm Axle.step]
2026-07-28 adding the scissor lift spacer
    [Scissor Lift Arm Spacer.step]
2026-08-08 new nema 14 motor mount
    [Bottom Nema 14 Motor Mount.step]
2026-08-11 new top nema 11 motor mount
    [Top Nema 11 Motor Mount.step]
2026-08-14 assembled printer

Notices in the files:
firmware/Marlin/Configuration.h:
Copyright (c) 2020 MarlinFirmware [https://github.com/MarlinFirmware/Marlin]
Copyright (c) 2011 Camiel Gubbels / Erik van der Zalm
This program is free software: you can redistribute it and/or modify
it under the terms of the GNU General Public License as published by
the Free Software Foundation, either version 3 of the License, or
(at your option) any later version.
